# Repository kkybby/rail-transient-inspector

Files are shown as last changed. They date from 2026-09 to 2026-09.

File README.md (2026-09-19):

# LIMIT4

### Four limit-switch inputs for dual-actuator projects

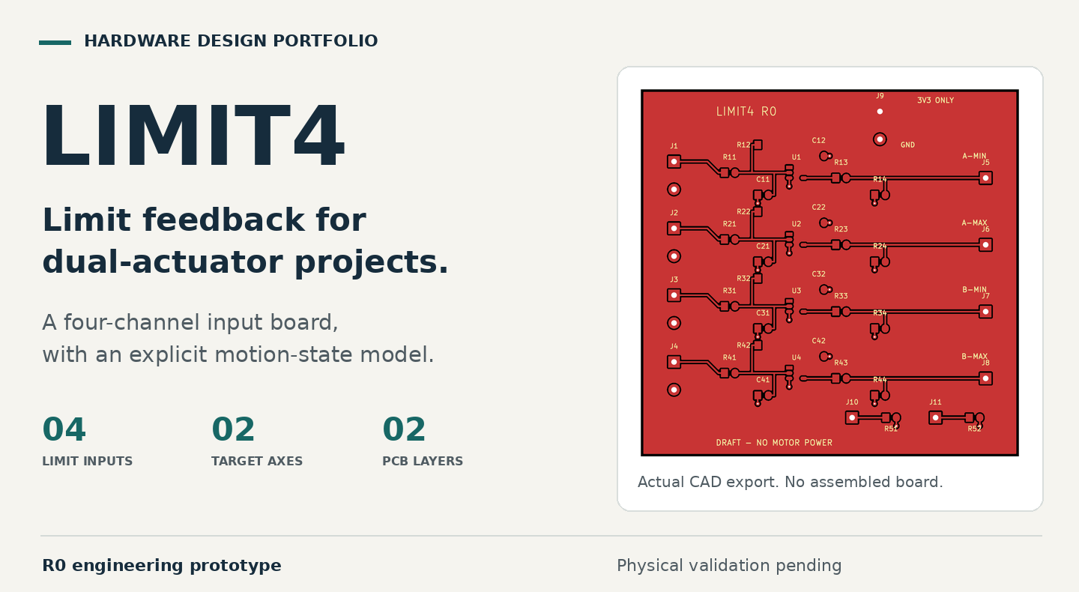
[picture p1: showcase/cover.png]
LIMIT4 hardware design portfolio, showing the actual PCB export


[中文介绍](README.zh-CN.md) | [Schematic](build/limit4-schematic.pdf) | [PCB source](hardware/limit4.kicad_pcb) | [Engineering details](docs/ENGINEERING.md)

**Stage: unbuilt engineering prototype.** The interface PCB and software checks are complete for this revision. The Pico 2 firmware is a dry-run build with motor outputs disabled.

## The problem

A small motorized prop has two distinct questions: did the controller accept the command, and did the mechanism reach its destination? A motor driver alone does not answer both.

LIMIT4 explores the interface between physical end stops and motion control. It provides four normally closed contact inputs for two actuator axes, with signal conditioning and a separate software model for stopped, moving, limit-open and fault states.

## The design contribution

**A board-level interface.** A two-layer, 68 x 66 mm PCB with four repeated input channels, local filtering, Schmitt-trigger conditioning and defined output biasing. Editable schematic, layout and project-local libraries are included.

**Explicit motion states.** The independent controller code handles directional limits, invalid reversal requests, driver-fault input, command timeout and communication expiry. A switch closing again does not automatically restart a stopped request. These behaviors are covered by host tests; physical stopping is not yet validated.

**Traceable engineering.** Component assumptions, reset and power-state analysis, source-to-layout checks and a bench qualification plan are retained with the design.

## What is new, and what is reused?

| This project's contribution | Existing upstream platform |
|---|---|
| LIMIT4 input-conditioning PCB and local CAD libraries | OpenDualMotorDriver motor-power motherboard |
| Independent motion-state code and dry-run wrapper | Existing bridge and current-sensing hardware |
| Interface analysis, tests and verification records | Published motherboard interfaces |

The reference platform is [OpenDualMotorDriver by Milos Rasic](https://github.com/MilosRasic98/OpenDualMotorDriver). The original power board has not been redesigned or qualified by this project. No original firmware or hardware photographs are presented as new work. Development of this extension was AI-assisted.

## Verification so far

The recorded KiCad checks report **zero ERC errors, zero DRC errors and zero unrouted items**. Cross-file checks cover 84 connected pin assignments and four NC pads. The motion-state tests pass 47 assertions, and the output-disabled program cross-compiles for Pico 2.

[Check records](build/check-summary.json) | [Software test record](build/host-tests.txt) | [Validation scope](docs/VALIDATION.md)

**Still to validate:** assembly, actual contacts, power sequencing, noise response and motor integration. A limit-loop opening cannot distinguish an endpoint from a broken wire. R0 is not released for fabrication, motor operation or personnel protection.

## Explore the work

Start with the [schematic PDF](build/limit4-schematic.pdf) and [PCB layout](build/pcb-top.png). The [engineering guide](docs/ENGINEERING.md) collects the BOM, interface mapping, calculations, source files and reproduction steps.

Hardware: [CERN-OHL-S-2.0](LICENSES/CERN-OHL-S-2.0.txt). Independent firmware: [MIT](firmware/LICENSE). [Attribution and upstream licence discrepancy](docs/PROVENANCE.md).

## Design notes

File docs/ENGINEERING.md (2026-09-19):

# LIMIT4 engineering reference

[Project overview](../README.md) | [中文作品介绍](../README.zh-CN.md)

This page contains detailed review and reproduction material. R0 is an unbuilt engineering prototype, not a manufacturing or motor-operation release.

## Design files

| Material | Source |
|---|---|
| Schematic | [PDF](../build/limit4-schematic.pdf), [editable KiCad file](../hardware/limit4.kicad_sch) |
| PCB | [Layout image](../build/pcb-top.png), [editable PCB](../hardware/limit4.kicad_pcb), [project settings](../hardware/limit4.kicad_pro) |
| Libraries | [Footprints](../hardware/LIMIT4.pretty), [symbols](../hardware/RTI.kicad_sym) |
| Parts and nets | [BOM qualification](../hardware/BOM.csv), [electrical manifest](../hardware/design.json) |
| Design reasoning | [Evidence](EVIDENCE.md), [qualification limits](QUALIFICATION.md), [power/reset states](STATES.md) |
| Integration | [Interface map and upstream issues](INTEGRATION.md) |
| Firmware | [Independent state model](../firmware/motion.hpp), [output-disabled Pico 2 program](../firmware/pico_dryrun.cpp) |
| Validation | [Scope and release gates](VALIDATION.md), [ERC](../build/erc.json), [DRC](../build/drc.json), [connectivity](../build/connectivity.txt), [host tests](../build/host-tests.txt) |
| Attribution | [Provenance](PROVENANCE.md), [hardware notice](../LICENSE-HARDWARE), [complete hardware licence](../LICENSES/CERN-OHL-S-2.0.txt), [software licence](../firmware/LICENSE) |

## Reproduction

Use KiCad 10.0.6 and the system Python installation that provides its matching `pcbnew` module. Native CAD and local libraries can also be opened directly without regeneration.

```sh
mkdir -p build
python3 tools/build_hardware.py
python3 tools/layout_schematic.py
python3 tools/polish_symbols.py
kicad-cli sch export pdf -o build/limit4-schematic.pdf hardware/limit4.kicad_sch
kicad-cli sch export netlist --format kicadxml -o build/limit4.xml hardware/limit4.kicad_sch
kicad-cli sch erc --format json -o build/erc.json hardware/limit4.kicad_sch
kicad-cli pcb drc --format json -o build/drc.json hardware/limit4.kicad_pcb
python3 tools/check_connectivity.py
c++ -std=c++17 -Wall -Wextra -Werror tests/motion_test.cpp -o /tmp/limit4-test
/tmp/limit4-test
python3 tools/build_showcase.py
```

The generator overwrites generated CAD. Incorporate any manual edits deliberately. Symbol polishing changes label visibility and the power-flag graphic only. Pin definitions, wires, net labels, PCB geometry and firmware are compared before and after that step; its record is in `build/symbol-display-audit.json`.

## Reading the checks

ERC, DRC and matching net names validate configured file rules and source consistency. They do not prove electrical margins, correct physical assembly, appropriate contact wetting, stop distance or safety. The 47 host assertions exercise software requests. The Pico 2 compile uses a dry-run program with physical PWM and RESET outputs held low.

Full passive part qualification, host silicon revision, power sequencing, motor/contact selection and physical tests remain open. Do not order parts or fabrication from the draft BOM without resolving the release gates.

## Presentation assets

The cover is built from `build/pcb-top.png`, an actual CAD copper-layer export. It is resized and placed in a typographic layout; it is not a product photograph or a claim that a board has been assembled. The source fingerprint is recorded in `showcase/asset-provenance.json`.

The repository overview is a GitHub README, not a deployed application website. The hardware project currently lives on `hardware/dual-actuator-controller-r0`; the software application remains on `main`.

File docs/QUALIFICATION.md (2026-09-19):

# Qualification boundaries / engineering review, 2026-09-19

Read this with EVIDENCE.md and STATES.md. These restrictions take precedence over any simplified interpretation of the numerical examples.

1. **RP2350 A2 erratum E9:** the normal input-leakage specification is not a worst-case substitute for the erratum. The 6k8 resistor is chosen within the documented external pull-down workaround; this does not establish all combinations of supply, ramp, internal pulls and disconnects. The 0.681 V unexpected-pull-up estimate in EVIDENCE.md excludes additional erratum-related current and therefore is NOT a guarantee for an A2 input with its internal pull-up enabled. Intended firmware disables internal pulls. Powered active-buffer high-drive margin also remains subject to the actual silicon and load. Do not use the approximately 120 uA typical erratum figure as a maximum.

2. **Supply-dependent specifications:** a VOH/VOL limit tested at 3.0 V and a receiver threshold specified at 3.3 V do not automatically prove every corner of an assumed 3.135–3.465 V shared rail. Interpolated Schmitt thresholds and RC crossing times are design estimates. The full range requires independent analysis and physical supply/temperature sweeps. Absolute maximum ratings are never an operating recommendation.

3. **Power sequencing:** separate buffer/host supplies are excluded. Below the logic devices' operating range, output behavior is unspecified. A common ground break is not covered by Ioff or the external pull-down. Partial-power and ramp calculations support a prototype concept only; no fail-safe guarantee is made.

4. **Reset provisions:** R51/R52 have an intended powered-driver bias calculation. They provide no protection if omitted or not connected to the verified motherboard nets. Unpowered driver input behavior, source-board stuffing, watchdog behavior and back-power paths still require qualification. RESET low means the specified electrical high-impedance/coast state, not instantaneous mechanical stopping.

5. **Contact and passive selection:** the NC contact must be qualified at the proposed sub-mA wetting current. Cable resistance/capacitance are engineering assumptions. Full passive MPNs, tolerances, voltage ratings, leakage, dimensions and footprints remain unresolved; the BOM is not a manufacturing authorization. Long-cable ESD, industrial inputs and surge protection are outside R0.

6. **Evidence interpretation:** ERC, DRC and netlist checks validate configured file rules and consistency, not these electrical assumptions. The host tests validate software requests only. The cross-compiled Pico program continuously holds real motor outputs off. There is no motor drive release, guaranteed stop latency or safety certification.

R0 remains NOT FOR FABRICATION and NOT FOR MOTOR OPERATION until these gates and the physical validation plan are resolved.

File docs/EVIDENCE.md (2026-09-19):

# Electrical evidence and calculations / R0

## Exact devices / documents

Extension IC: TI **SN74LVC1G14DBVR**, DBV 5-pin SOT-23. Product https://www.ti.com/product/SN74LVC1G14 ; data sheet **SCES218AA, October2025**, https://www.ti.com/lit/ds/symlink/sn74lvc1g14.pdf . No externally selectable silicon stepping was established; physical lot remains unknown. Input is high-impedance Schmitt CMOS; output is push-pull with Ioff support, not open drain. No internal resistor to VCC is assumed.

Host: upstream **Pico2/RP2350A module**. Pico2 datasheet Release5, build03/07/2026 d4e0f1799616: https://datasheets.raspberrypi.com/pico/pico-2-datasheet.pdf . RP2350 datasheet build2025-07-29 d126e9e-clean: https://datasheets.raspberrypi.com/rp2350/rp2350-datasheet.pdf . Actual module stepping must be identified; A2 erratum E9 is considered and B2 is not assumed.

Existing driver: **DRV8412DDWR**, DDW44 HTSSOP+PowerPAD. **SLES242H, July2024**: https://www.ti.com/lit/ds/symlink/drv8412.pdf . Product/EVM pages inspected: https://www.ti.com/product/DRV8412 and https://www.ti.com/tool/DRV8412DDWEVM . EVM user-guide download did not open in this session. No separate applicable errata was established from the inspected pages; this is not proof none exists. Full power-stage qualification remains open.

## Cell-by-cell evidence log

TI printed page equals PDF ordinal except unnumbered mechanical addendum. RP2350 viewer index is explicitly zero-based below.

| Document/table | Page | Row / column | Minimal relevant cell / condition | Supported conclusion |
|---|---|---|---|---|
| SCES218AA Table4-1 | print4/PDF4 | A,GND,Y,VCC / DBV | 2,3,4,5 | Exact DBV pin map |
| Same footnote1 | print4/PDF4 | NC | no internal connection, soldered | NC1 left electrically unconnected, pad retained |
| SCES218AA5.5 | print7/PDF7 | VT+ /3V min,max | 1.5,1.87V | Tested rising threshold |
| Same | print7/PDF7 | VT- /DBV /3V /-40..85C | 0.84,1.14V | Tested falling threshold; not DPW row |
| Same | print7/PDF7 | VT+4.5Vmax;VT-4.5Vmin | 2.74V;1.41V | Adjacent points for engineering interpolation |
| Same | print7/PDF7 | VOH /3V /-16mA /min | 2.4V | Loaded high output at tested condition |
| Same | print7/PDF7 | VOL /3V /16mA /max | 0.4V | Loaded low output at tested condition |
| Same | print7/PDF7 | II /VI5.5V or GND,VCC0..5.5 | +/-5uA | Input leakage, no assumed internal pull |
| Same | print7/PDF7 | Ioff /VCC0,VI or VO5.5V | +/-10uA | Qualified poweroff leakage |
| Same | print7/PDF7 | ICC /IO0,VI5.5V or GND | 10uAmax | Static rail-level current, not transient current |
| SCES218AA5.1/5.3 | print5/6/PDF5/6 | recommended input/output | 0..5.5V /0..VCC | No external12/24V inputs; abs-max not normal operation |
| SCES218AA7.2.3 Fig7-2 | print13/PDF13 | explanation | interpolation between table points | An engineering estimate, not a new independently tested limit |
| SCES218AA7.3 | print13/PDF13 | bypass | 0.1uF near VCC | Local Cx2 purpose |
| DBV0005A4214839/K08/2024 | PDF39, unnumbered | land pad/column/row pitch | 1.1x0.6mm /2.6mm /0.95mm | Custom DBV copper geometry |
| RP2350 Table1436,14.9.4 | print1339..1340,viewer1339..1340 | VIH/VIL at IOVDD3.3 | 2.0Vmin /0.8Vmax | GPIO compatibility comparison |
| Same | print1340,viewer1340 | VOH2mAmin /inputpullup | 2.62V /32..86kOhm | Reset drive and unexpected pull-up calculation |
| RP2350-E9 | print1366..1367,viewer1366..1367 | A2 mitigation | external pull-down8.2kOhm or less | 6k8+1% is within explicit workaround |
| SLES242H Table4-1 | print3/PDF3 | DDW RESET_AB/CD | pins16/6 | Not adjacent DRV8432 column |
| SLES242H5.7 | print7/PDF7 | RESETVIH/VIL,leak | 2Vmin /0.8Vmax /+/-100uA | Powered reset bias calculation |
| SLES242H6.3.3 | print13/PDF13 | reset mode | bridge high impedance | Coast/Hi-Z, not guaranteed mechanical braking |

E9's approximately120uA is typical, never treated as a guaranteed maximum. The explicit8.2k workaround is used instead. Active buffer drive helps when powered;6k8 also biases a disconnected/unpowered output. The standard GPIO1uA leakage applies only where the erratum does not invalidate it.

## Circuit / explicit assumptions

Engineering target: shared nominal3.3V, assumed3.135..3.465V; initial bench0..50C; NC contact+cable resistance<=10Ohm; cable capacitance<=1nF. These are qualification targets, not user equipment facts. Long-wire, industrial ESD/surge and independently powered hosts are excluded.

LOOP--330R--FILT; FILT--4k7--3V3; FILT--10nF--GND; U.A=FILT; U.Y--470R--ALLOW; ALLOW--6k8--GND. Four100nF bypasses. Resistors1%, filterC5% C0G targets. Exact passive MPNs are not yet qualified and are labelled SPEC_ONLY_MPN_PENDING in the BOM, preventing an unverified purchase recommendation.

Closed FILT worst at3.465V, series+contact343.3Ohm and pull4653Ohm:
`Vclosed <= 3.465*343.3/(4653+343.3) + 5uA*(4653||343.3) = 0.240V`.
Open FILT at minimum supply:
`Vopen >= 3.135-5uA*4747 = 3.111V`.
Contamination leakage must be added after qualification. The3V and4.5V threshold rows bracket an engineering interpolation as illustrated by Fig7-2; supply/temperature sweeps are still required. Wetting current is approximately0.62..0.70mA: do not assume an arbitrary micro-switch supports that low-current operation.

Using tested VOH2.4V, output resistor474.7Ohm and pull6732Ohm:
`VALLOW >= 2.4*6732/(6732+474.7)-1uA*6732 = 2.235V`, margin0.235V over GPIO VIH2.0V at3.3V. Tested VOL0.4V is below0.8V. The loaded specification is evaluated at its actual test point; extending to the full assumed common-rail range remains prototype qualification. Actual static load<0.52mA per output, below the16mA test condition. Intended resistor loss is only a few mW.

Buffer poweroff: `10uA*6868Ohm =0.069V`. Unexpected host internal pull-up32kOhm at3.465V gives `3.465*6868/(32000+6868)=0.612V`; adding0.069V yields0.681V<0.8V under this defined model. This does not cover ground loss or an actively driven host output. GPIO inputs have internal pulls disabled in the intended firmware.

Accidental opposing push-pull outputs are current-limited nominally by470R: `3.465/465.3=7.45mA`. This is mitigation of accidental DC contention, not a valid operating mode or a verified transient-clamp budget. Positive/negative transients and separate supply behavior are not certified.

Filter open tau maximum=`4747*(10.5nF+1nF)=54.59us`. The table-based interpolated rising threshold at3.465V is about2.14V. Crossing is on the order of50..65us for these assumptions. This is not a motor-stop guarantee: polling, scheduling, bounce, driver behavior and inertia add delay. Startup capacitor charging can temporarily make ALLOWhigh, so the controller requires stable inputs and explicit arm. No automatic restart is implemented.

Optional RESET2k2 pulls: powered-driver leakage100uA times Rmax2222Ohm is0.2222V<0.8V. At GPIO VOHmin2.62V the load including100uA is about1.30mA, below the2mA output test; high-level margin is0.62V. Driver leakage was specified under powered conditions; fully independent poweroff still needs investigation. The driver's ~1kOhm internal pull-down row applies to each OUTPUT half-bridge, not RESET. No invented RESET internal pull is used.

## Classification

Cx2: data-sheet recommended bypass. R x1/x2/x3/x4, Cx1,R51/R52: computed engineering selections under stated assumptions, require physical validation. Host mapping: source-verified but assembled continuity pending. No unverified motor-current, clamp/ESD or connector behavior enters a production connection table. R0 is not a production release.

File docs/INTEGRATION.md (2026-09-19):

# Integration / engineering suggestion only

This is a wired expansion, not a mechanically interchangeable motherboard. There are no motor-current paths on LIMIT4. Verify actual board revision and continuity before soldering.

| LIMIT4 | Purpose | Intended upstream net |
|---|---|---|
| J9.1 | Shared3V3 | CN7.1 /host3V3 |
| J9.2 | Ground | CN7.5/GND |
| J5.1 | A_MIN ALLOW | GPIO16/CN7.2/SPI_MISO |
| J6.1 | A_MAX ALLOW | GPIO17/CN7.4/SPI_CS |
| J7.1 | B_MIN ALLOW | GPIO18/CN7.6/SPI_SCK |
| J8.1 | B_MAX ALLOW | GPIO19/CN7.3/SPI_MOSI |
| J10.1 | Optional reset pull | RESET_AB/GPIO12/DRV8412DDW16 |
| J11.1 | Optional reset pull | RESET_CD/GPIO9/DRV8412DDW6 |
| J1..J4.1 | Contact signal | NC switch to corresponding pin2 |
| J1..J4.2 | Contact return | GND |

Mapping evidence: upstream schematic pages2/3 and BoardConfig.h at pinned commit; TI SLES242H Table4-1 DDW column. Classification: engineering connection suggestions after source review, pending physical continuity and power-state checks. The4k7/6k8/470/330 and2k2 parts' calculations are in EVIDENCE.md.

All J footprints are plated solder-wire pads with1mm holes; pin1 is rectangular. No mating connector/strain relief/wire model is qualified. Upstream CN7 drawing has a part-name suggesting a different contact count; do not assume an off-the-shelf cable maps correctly.

Axis A is bridgeAB, PWM_A GPIO11/PWM_B GPIO13. B is bridgeCD, PWM_C GPIO8/PWM_D GPIO10. Direction versus actual travel must be checked. Four limit signals consume the original SPI GPIOs; SPI peripherals cannot run concurrently.

Review finding: firmware axis0 samples GPIO26/ACS722_OUT1, while schematic links OUT1 to CD and OUT2/GPIO27 to AB. This is a source inconsistency to investigate, not a measured hardware failure. R0 uses no current measurement for protection. Confirm physical netlist/mapping before current-based stopping. Existing driver OCP is not automatically appropriate for a small motor/gearbox.

Original power schematic shows external5V attached to Pico VBUS and external3V3 arrangements. USB plus external power, regulator reverse current and actual stuffing need a separate audit. Avoid simultaneous unverified power sources. Native source/README voltage claims are not adopted as our ratings.

Real drive is compile-blocked. Required before enabling: motor full model/voltage/stall current/inertia, micro-switch model/wetting requirements, guard/stop strategy, actual part revisions, power-sequence tests. Driver RESETlow gives Hi-Z/coast with the specified weak output pull-down; it does not guarantee instantaneous braking or zero travel.

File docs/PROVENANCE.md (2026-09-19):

# Provenance / changes / licensing

Upstream: Miloš Rašić, OpenDualMotorDriver, commit `9a938240a8053269b1b8786dccdb6d541cb7396c`.

Original files inspected: `Hardware/ProPrj_Dual_Motor_Driver_2026-05-02.epro`, three schematic PNGs, `Firmware/PicoDualMotorDriver/BoardConfig.h`, `DualMotorController.cpp`, README, LICENSE and LICENSE-HARDWARE. The epro is an EasyEDA Pro archive, editor metadata 2.2.45.4. Its source motherboard has LT8350-based12V gate-drive power, a5V converter and a3.3V regulator; the derivative has not requalified these sections. No upstream power ratings are adopted as our measured specifications.

**Licence discrepancy:** the pinned README/Hardware notice say firmware and host software are MIT; the actual root LICENSE is the GNU GPL version3 text. Our earlier claim that all software was MIT was overbroad. This release does not copy, modify or redistribute upstream firmware. The new small state machine and dry-run wrapper are independent code; pin/net assignments are documented interfaces. Any later reuse must first resolve the applicable terms.

The upstream `LICENSE-HARDWARE` explicitly assigns CERN-OHL-S-2.0 to the hardware. The new extension hardware, schematic, board, electrical manifest, design generator and technical hardware documents are offered under CERN-OHL-S-2.0. Preserve attribution and source location. No endorsement by the original author, TI, Raspberry Pi, CERN or Element14 is implied.

New contribution: four NC front ends, defined default-low outputs, two external driver-reset pulls, four-input harness map, independent state machine, tests, native CAD and source-to-board checks. Original main bridge PCB remains unmodified and linked, not claimed as a newly routed derivative. Original photographs are not used as photographs of our product.

Official licence: https://ohwr.org/licences/ . The authoritative licence, not this summary, governs. AI-assisted design; no physical board, motor measurement or customer result is claimed.

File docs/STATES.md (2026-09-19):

# State / failure review

| Condition | Expected in stated model | Residual risk |
|---|---|---|
| Powered/NCclosed | FILTlow/ALLOWhigh | Contact wetting must be qualified |
| NCopens/either loopwire breaks | FILThigh/ALLOWlow; directional request stopped | Cannot distinguish endpoint/wirebreak; short defeats detection |
| MCU reset/high-Z | External2k2 aim to hold RESETlow | Physical rework and driver-powered leakage must be tested |
| RESET high/low | Enable /Hi-Z according to TI | Dry-run never drives high |
| GPIO mistakenly output |470R mitigates contention | Invalid operating state, no correctness claim |
| Buffer off/hoston |Ioff and6k8 model yields low | Shared supplies are intended; verify GPIO/ground |
| Bufferon/hostoff |Buffer can drive hostpad |Independent supplies prohibited; abs-max not permission |
| Ramp/brownout |Logic below supplymin unspecified |Explicit arm; measure reset sequence |
| Sleep/wake |Require reset and newarm |Sleep routine not implemented |
| Driverfault/both limitsopen |All requests disabled |OCP may not protect gearbox |
| Communication expires |Requests cleared at500ms policy |Host test only; no measured latency |
| Firmware lockup |Watchdog100ms request/reset pulls |Actual watchdog behavior untested |
| Reverse request while moving |Rejected |Qualified PWM/deadtime backend not implemented |
| Contact recloses after stop |No automatic restart |Bounce/EMI still require testing |
| Common groundbreak |Undefined references |Not fail-safe; independent cutoff needed |

No optocoupler, MOSFET, level translator or TVS is installed on this controlled shared-rail dry-contact interface. Their absence restricts use; it is not a robustness claim. Long cables/industrial24V sensors need a separate protection design. Local100nF capacitors bypass each gate;10nF filters and external pulls have explicit calculations, not generic boilerplate.

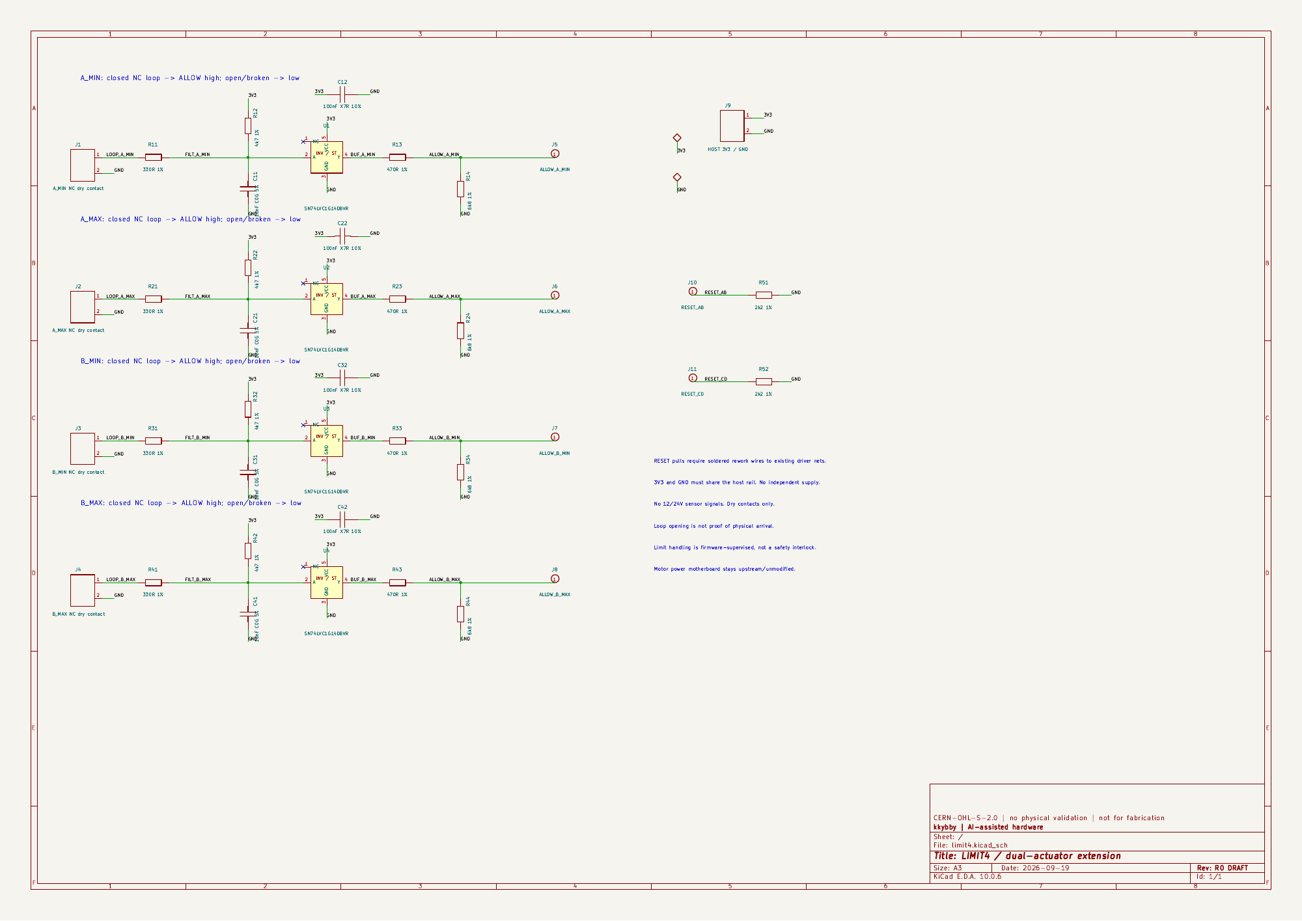
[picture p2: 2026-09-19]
build/schematic.png

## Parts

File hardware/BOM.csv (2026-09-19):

Reference | Value | Candidate_MPN | Footprint | Qualification
J1 | A_MIN NC dry contact |  | 1mm solder-wire holes | Wire termination only; no mating connector claimed
R11 | 330R 1% | SPEC_ONLY_MPN_PENDING | 0805 | Exact TI IC checked; passive sourcing/assembly approval pending
R12 | 4k7 1% | SPEC_ONLY_MPN_PENDING | 0805 | Exact TI IC checked; passive sourcing/assembly approval pending
C11 | 10nF C0G 5% | SPEC_ONLY_MPN_PENDING | 0805 | Exact TI IC checked; passive sourcing/assembly approval pending
U1 | SN74LVC1G14DBVR | SN74LVC1G14DBVR | DBV-5 | Exact TI IC checked; passive sourcing/assembly approval pending
C12 | 100nF X7R 10% | SPEC_ONLY_MPN_PENDING | 0805 | Exact TI IC checked; passive sourcing/assembly approval pending
R13 | 470R 1% | SPEC_ONLY_MPN_PENDING | 0805 | Exact TI IC checked; passive sourcing/assembly approval pending
R14 | 6k8 1% | SPEC_ONLY_MPN_PENDING | 0805 | Exact TI IC checked; passive sourcing/assembly approval pending
J5 | ALLOW_A_MIN |  | 1mm solder-wire holes | Wire termination only; no mating connector claimed
J2 | A_MAX NC dry contact |  | 1mm solder-wire holes | Wire termination only; no mating connector claimed
R21 | 330R 1% | SPEC_ONLY_MPN_PENDING | 0805 | Exact TI IC checked; passive sourcing/assembly approval pending
R22 | 4k7 1% | SPEC_ONLY_MPN_PENDING | 0805 | Exact TI IC checked; passive sourcing/assembly approval pending
C21 | 10nF C0G 5% | SPEC_ONLY_MPN_PENDING | 0805 | Exact TI IC checked; passive sourcing/assembly approval pending
U2 | SN74LVC1G14DBVR | SN74LVC1G14DBVR | DBV-5 | Exact TI IC checked; passive sourcing/assembly approval pending
C22 | 100nF X7R 10% | SPEC_ONLY_MPN_PENDING | 0805 | Exact TI IC checked; passive sourcing/assembly approval pending
R23 | 470R 1% | SPEC_ONLY_MPN_PENDING | 0805 | Exact TI IC checked; passive sourcing/assembly approval pending
R24 | 6k8 1% | SPEC_ONLY_MPN_PENDING | 0805 | Exact TI IC checked; passive sourcing/assembly approval pending
J6 | ALLOW_A_MAX |  | 1mm solder-wire holes | Wire termination only; no mating connector claimed
J3 | B_MIN NC dry contact |  | 1mm solder-wire holes | Wire termination only; no mating connector claimed
R31 | 330R 1% | SPEC_ONLY_MPN_PENDING | 0805 | Exact TI IC checked; passive sourcing/assembly approval pending
R32 | 4k7 1% | SPEC_ONLY_MPN_PENDING | 0805 | Exact TI IC checked; passive sourcing/assembly approval pending
C31 | 10nF C0G 5% | SPEC_ONLY_MPN_PENDING | 0805 | Exact TI IC checked; passive sourcing/assembly approval pending
U3 | SN74LVC1G14DBVR | SN74LVC1G14DBVR | DBV-5 | Exact TI IC checked; passive sourcing/assembly approval pending
C32 | 100nF X7R 10% | SPEC_ONLY_MPN_PENDING | 0805 | Exact TI IC checked; passive sourcing/assembly approval pending
R33 | 470R 1% | SPEC_ONLY_MPN_PENDING | 0805 | Exact TI IC checked; passive sourcing/assembly approval pending
R34 | 6k8 1% | SPEC_ONLY_MPN_PENDING | 0805 | Exact TI IC checked; passive sourcing/assembly approval pending
J7 | ALLOW_B_MIN |  | 1mm solder-wire holes | Wire termination only; no mating connector claimed
J4 | B_MAX NC dry contact |  | 1mm solder-wire holes | Wire termination only; no mating connector claimed
R41 | 330R 1% | SPEC_ONLY_MPN_PENDING | 0805 | Exact TI IC checked; passive sourcing/assembly approval pending
R42 | 4k7 1% | SPEC_ONLY_MPN_PENDING | 0805 | Exact TI IC checked; passive sourcing/assembly approval pending
C41 | 10nF C0G 5% | SPEC_ONLY_MPN_PENDING | 0805 | Exact TI IC checked; passive sourcing/assembly approval pending
U4 | SN74LVC1G14DBVR | SN74LVC1G14DBVR | DBV-5 | Exact TI IC checked; passive sourcing/assembly approval pending
C42 | 100nF X7R 10% | SPEC_ONLY_MPN_PENDING | 0805 | Exact TI IC checked; passive sourcing/assembly approval pending
R43 | 470R 1% | SPEC_ONLY_MPN_PENDING | 0805 | Exact TI IC checked; passive sourcing/assembly approval pending
R44 | 6k8 1% | SPEC_ONLY_MPN_PENDING | 0805 | Exact TI IC checked; passive sourcing/assembly approval pending
J8 | ALLOW_B_MAX |  | 1mm solder-wire holes | Wire termination only; no mating connector claimed
J9 | HOST 3V3 / GND |  | 1mm solder-wire holes | Wire termination only; no mating connector claimed
J10 | RESET_AB |  | 1mm solder-wire holes | Wire termination only; no mating connector claimed
R51 | 2k2 1% | SPEC_ONLY_MPN_PENDING | 0805 | Exact TI IC checked; passive sourcing/assembly approval pending
J11 | RESET_CD |  | 1mm solder-wire holes | Wire termination only; no mating connector claimed
R52 | 2k2 1% | SPEC_ONLY_MPN_PENDING | 0805 | Exact TI IC checked; passive sourcing/assembly approval pending

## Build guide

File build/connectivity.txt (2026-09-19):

84 populated pin/net assignments and 4 NC pads match schematic, PCB and manifest.
drc.json errors= 0 warnings= 0 unconnected= 0
erc.json errors= 0 warnings= 0 unconnected= 0

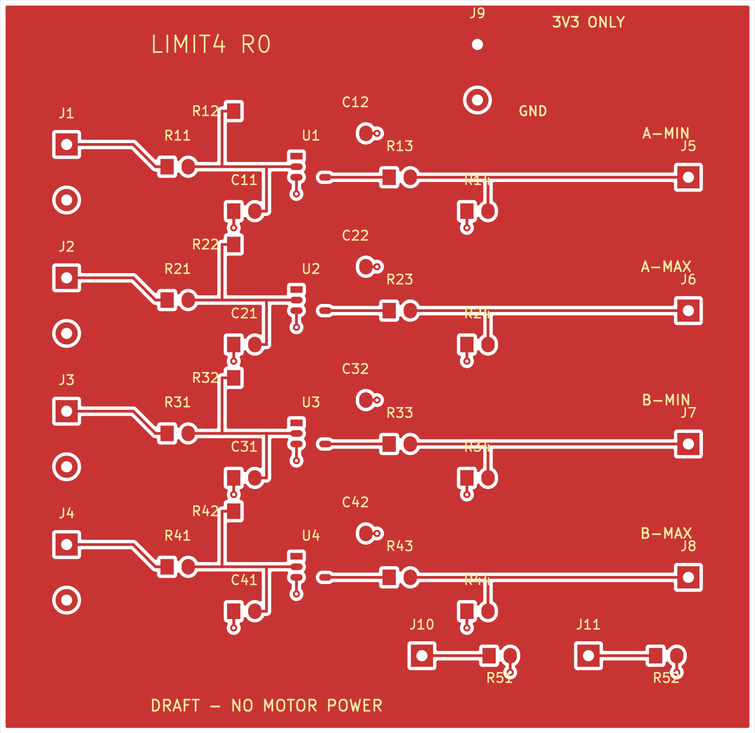
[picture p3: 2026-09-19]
build/pcb-top.png

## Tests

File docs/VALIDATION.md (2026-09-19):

# Validation record and remaining release gates

## Actually executed, 2026-09-19

| Check | Actual result |
|---|---|
| KiCad version | 10.0.6 |
| Native schematic/PCB | Generated and opened by KiCad CLI; PDF/SVG exports produced |
| ERC | 0 errors, 0 warnings |
| DRC | 0 errors, 0 warnings, 0 unconnected items |
| Manifest/schematic/PCB mapping | 41 components, 84 connected pin assignments, 4 NC pads checked |
| Independent host controller | 47 assertions passed using g++ C++17, -Wall -Wextra -Werror |
| Pico 2 cross-compilation | Success, pinned official Pico SDK 2.2.0 |
| Resulting ELF size | text 35168 bytes, data 0 bytes, BSS 3792 bytes |
| Assembly, flashing, motor tests | Not performed |

CAD source commit: `394ce1f6ac9a20584c89738f3ebd1a408357ee30`.
[CAD CI and generated-file publication](https://github.com/kkybby/rail-transient-inspector/actions/runs/35427853316).
Actual reports: [check summary](../build/check-summary.json), [connectivity](../build/connectivity.txt), [ERC](../build/erc.json), [DRC](../build/drc.json), [host assertions](../build/host-tests.txt).

Firmware source commit: `59efa8e02bd895e27b4777502ecefca23f3a303f`.
[Actual Pico 2 compile run](https://github.com/kkybby/rail-transient-inspector/actions/runs/35427472611).
Pico SDK commit: `a1438dff1d38bd9c65dbd693f0e5db4b9ae91779`.
Board target: `pico2`, `PICO_NO_PICOTOOL=1`; ELF/bin/hex compiled, no UF2 creation claimed. Firmware source has not changed after this successful run. The separate compile artifact contains logs and binaries; no flashing or hardware result follows from compilation.

Read [QUALIFICATION.md](QUALIFICATION.md) with the circuit estimates. No rule errors have been waived to manufacture a passing status. However, a passing automated check cannot establish physical correctness, appropriate component choice or safety.

## Physical release gates, still open

1. Confirm actual Pico 2 stepping and host PCB/epro/schematic correspondence, supply and USB connections.
2. Qualify full passive MPNs, footprint/body dimensions, voltage/tolerance/temperature/leakage and effective capacitance. Select the actual micro-switch for sub-mA wetting current.
3. With no motors connected, verify all loop states, unplugged wires, host harness, input modes and levels over the intended supply range. Record raw-input and ALLOW waveforms.
4. Characterize startup pulses, switch bounce and interference. Stop latency and stop distance must include mechanics and scheduling, not only an RC calculation.
5. Check reset, watchdog, invalid/reversed commands, limit-at-start, both loops open, driver fault, communication expiry and no automatic restart. A loop opening must not be labelled physical arrival without independent evidence.
6. Verify actual external reset-pull wiring and bias with each power state. Powered-input leakage does not cover all independent-off states.
7. Audit the upstream supply and current-channel mapping. Lock motor voltage/stall current/inertia, current limit, fuse, braking and guarding before implementing a real-drive backend.
8. Only then perform controlled low-energy motor testing with an independent cutoff and recorded results.

No fabrication Gerber package is issued in R0. Editable CAD is for review and iteration. No personnel-protection, human-trapping lock, lifting, vehicle or unguarded application is qualified. Firmware deliberately keeps physical outputs disabled.

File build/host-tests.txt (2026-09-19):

47 state-machine assertions passed; host logic only, no motor tests.

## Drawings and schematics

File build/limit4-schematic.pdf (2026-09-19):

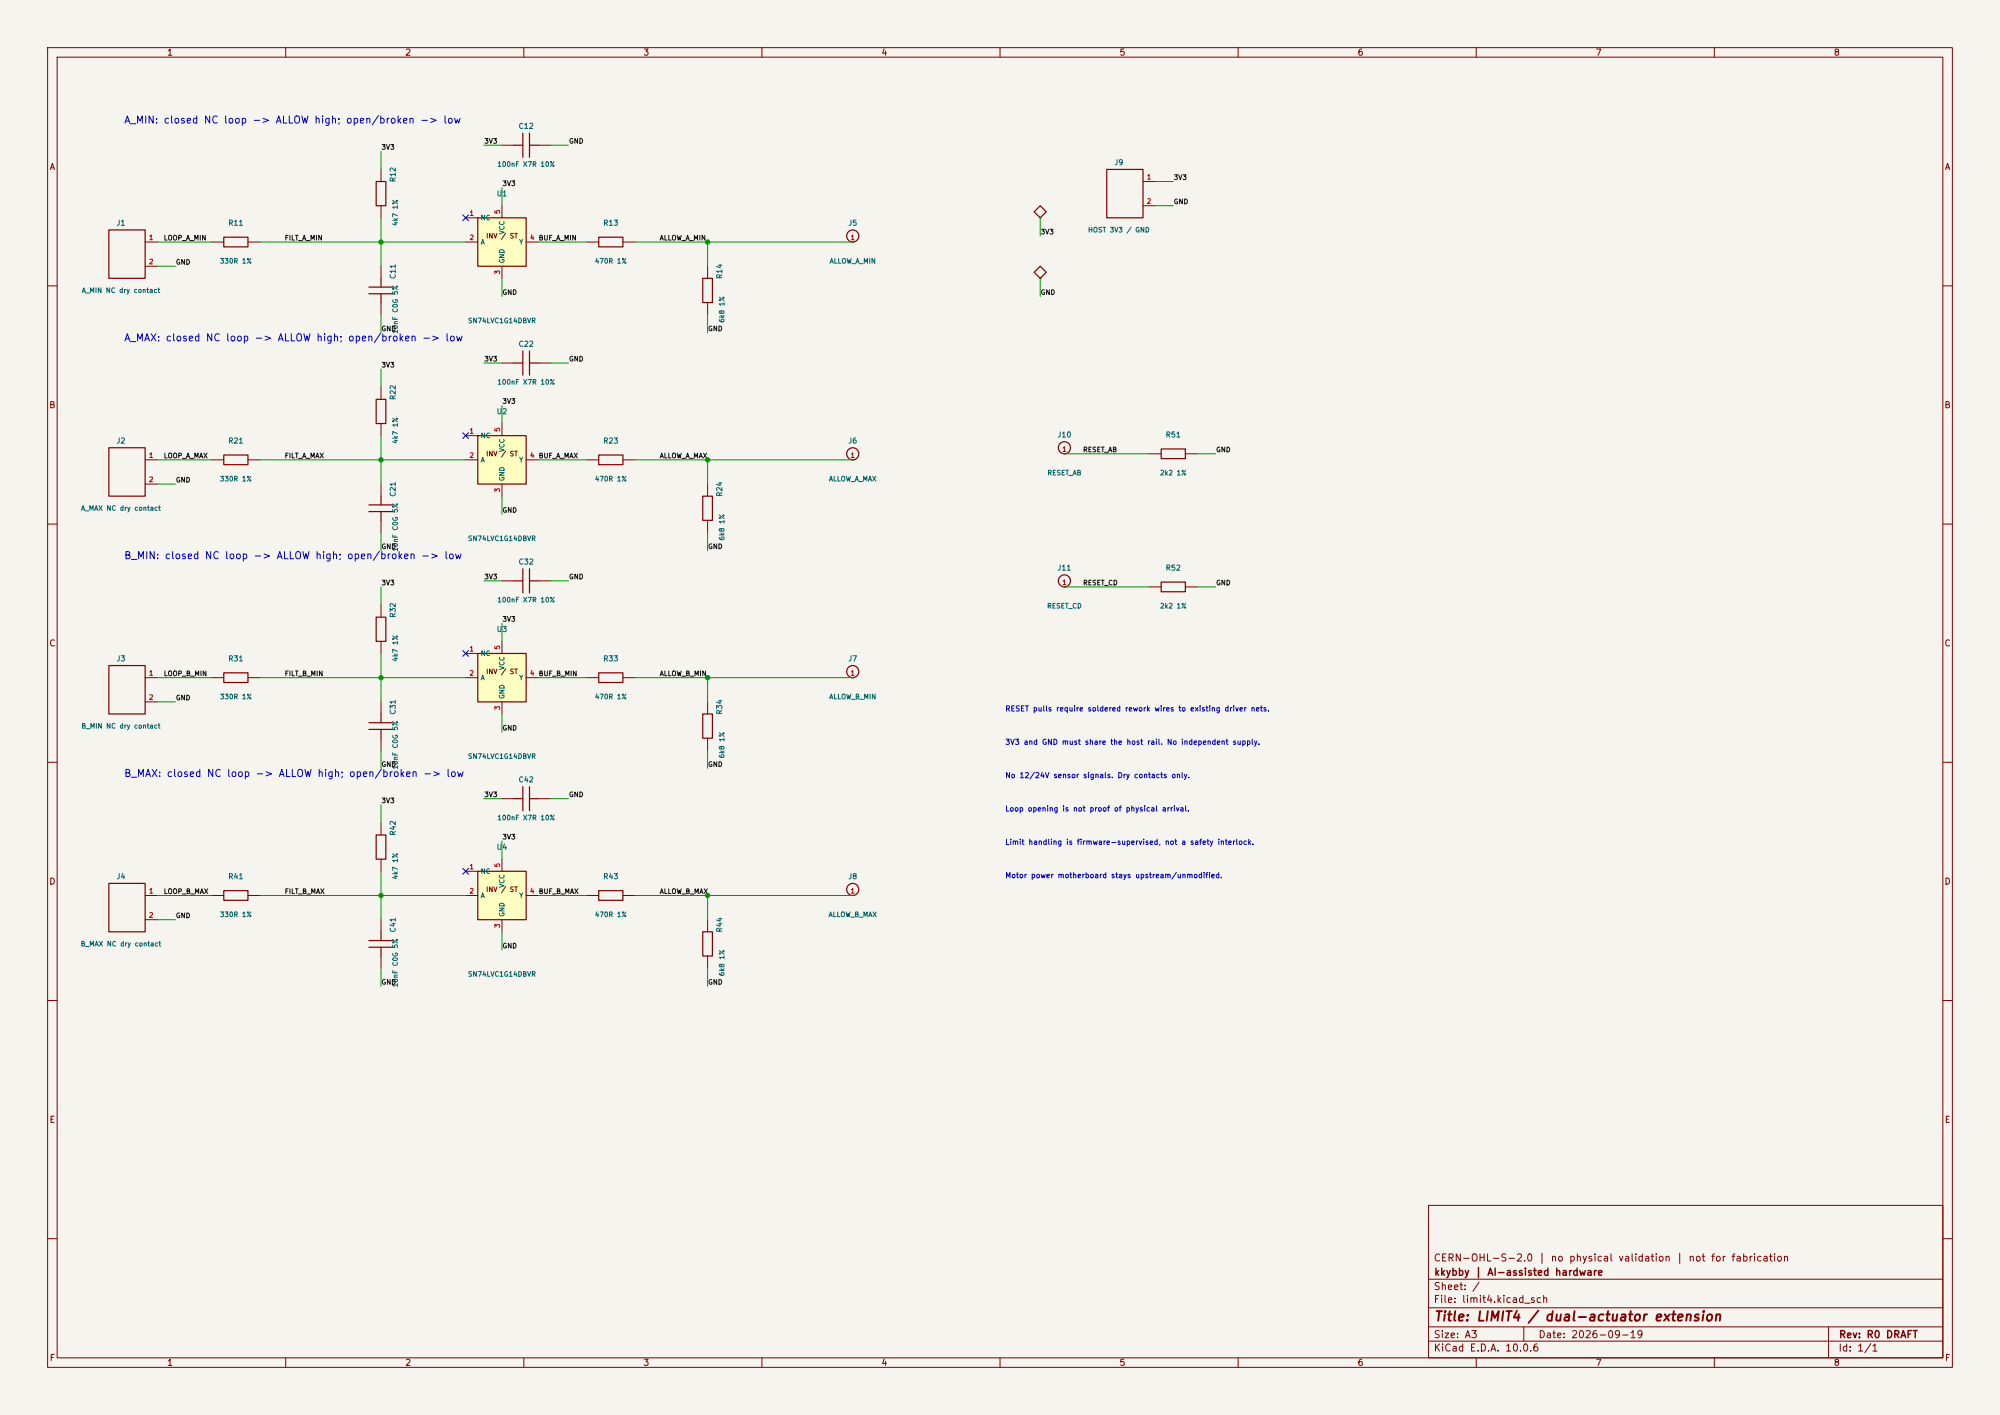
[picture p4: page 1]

A_MIN: closed NC loop -> ALLOW high; open/broken -> low

A_MAX: closed NC loop -> ALLOW high; open/broken -> low

CERN-OHL-S-2.0 | no physical validation | not for fabrication R24 6k8 1%

B_MIN: closed NC loop -> ALLOW high; open/broken -> low

RESET pulls require soldered rework wires to existing driver nets.

Loop opening is not proof of physical arrival. B_MAX: closed NC loop -> ALLOW high; open/broken -> low

kkybby | AI-assisted hardware
Sheet: /
File: limit4.kicad_sch
Title: LIMIT4 / dual-actuator extension

Size: A3 | Rev: R0 DRAFT | F Date: 2026-09-19
KiCad E.D.A. 10.0.6 | Id: 1/1

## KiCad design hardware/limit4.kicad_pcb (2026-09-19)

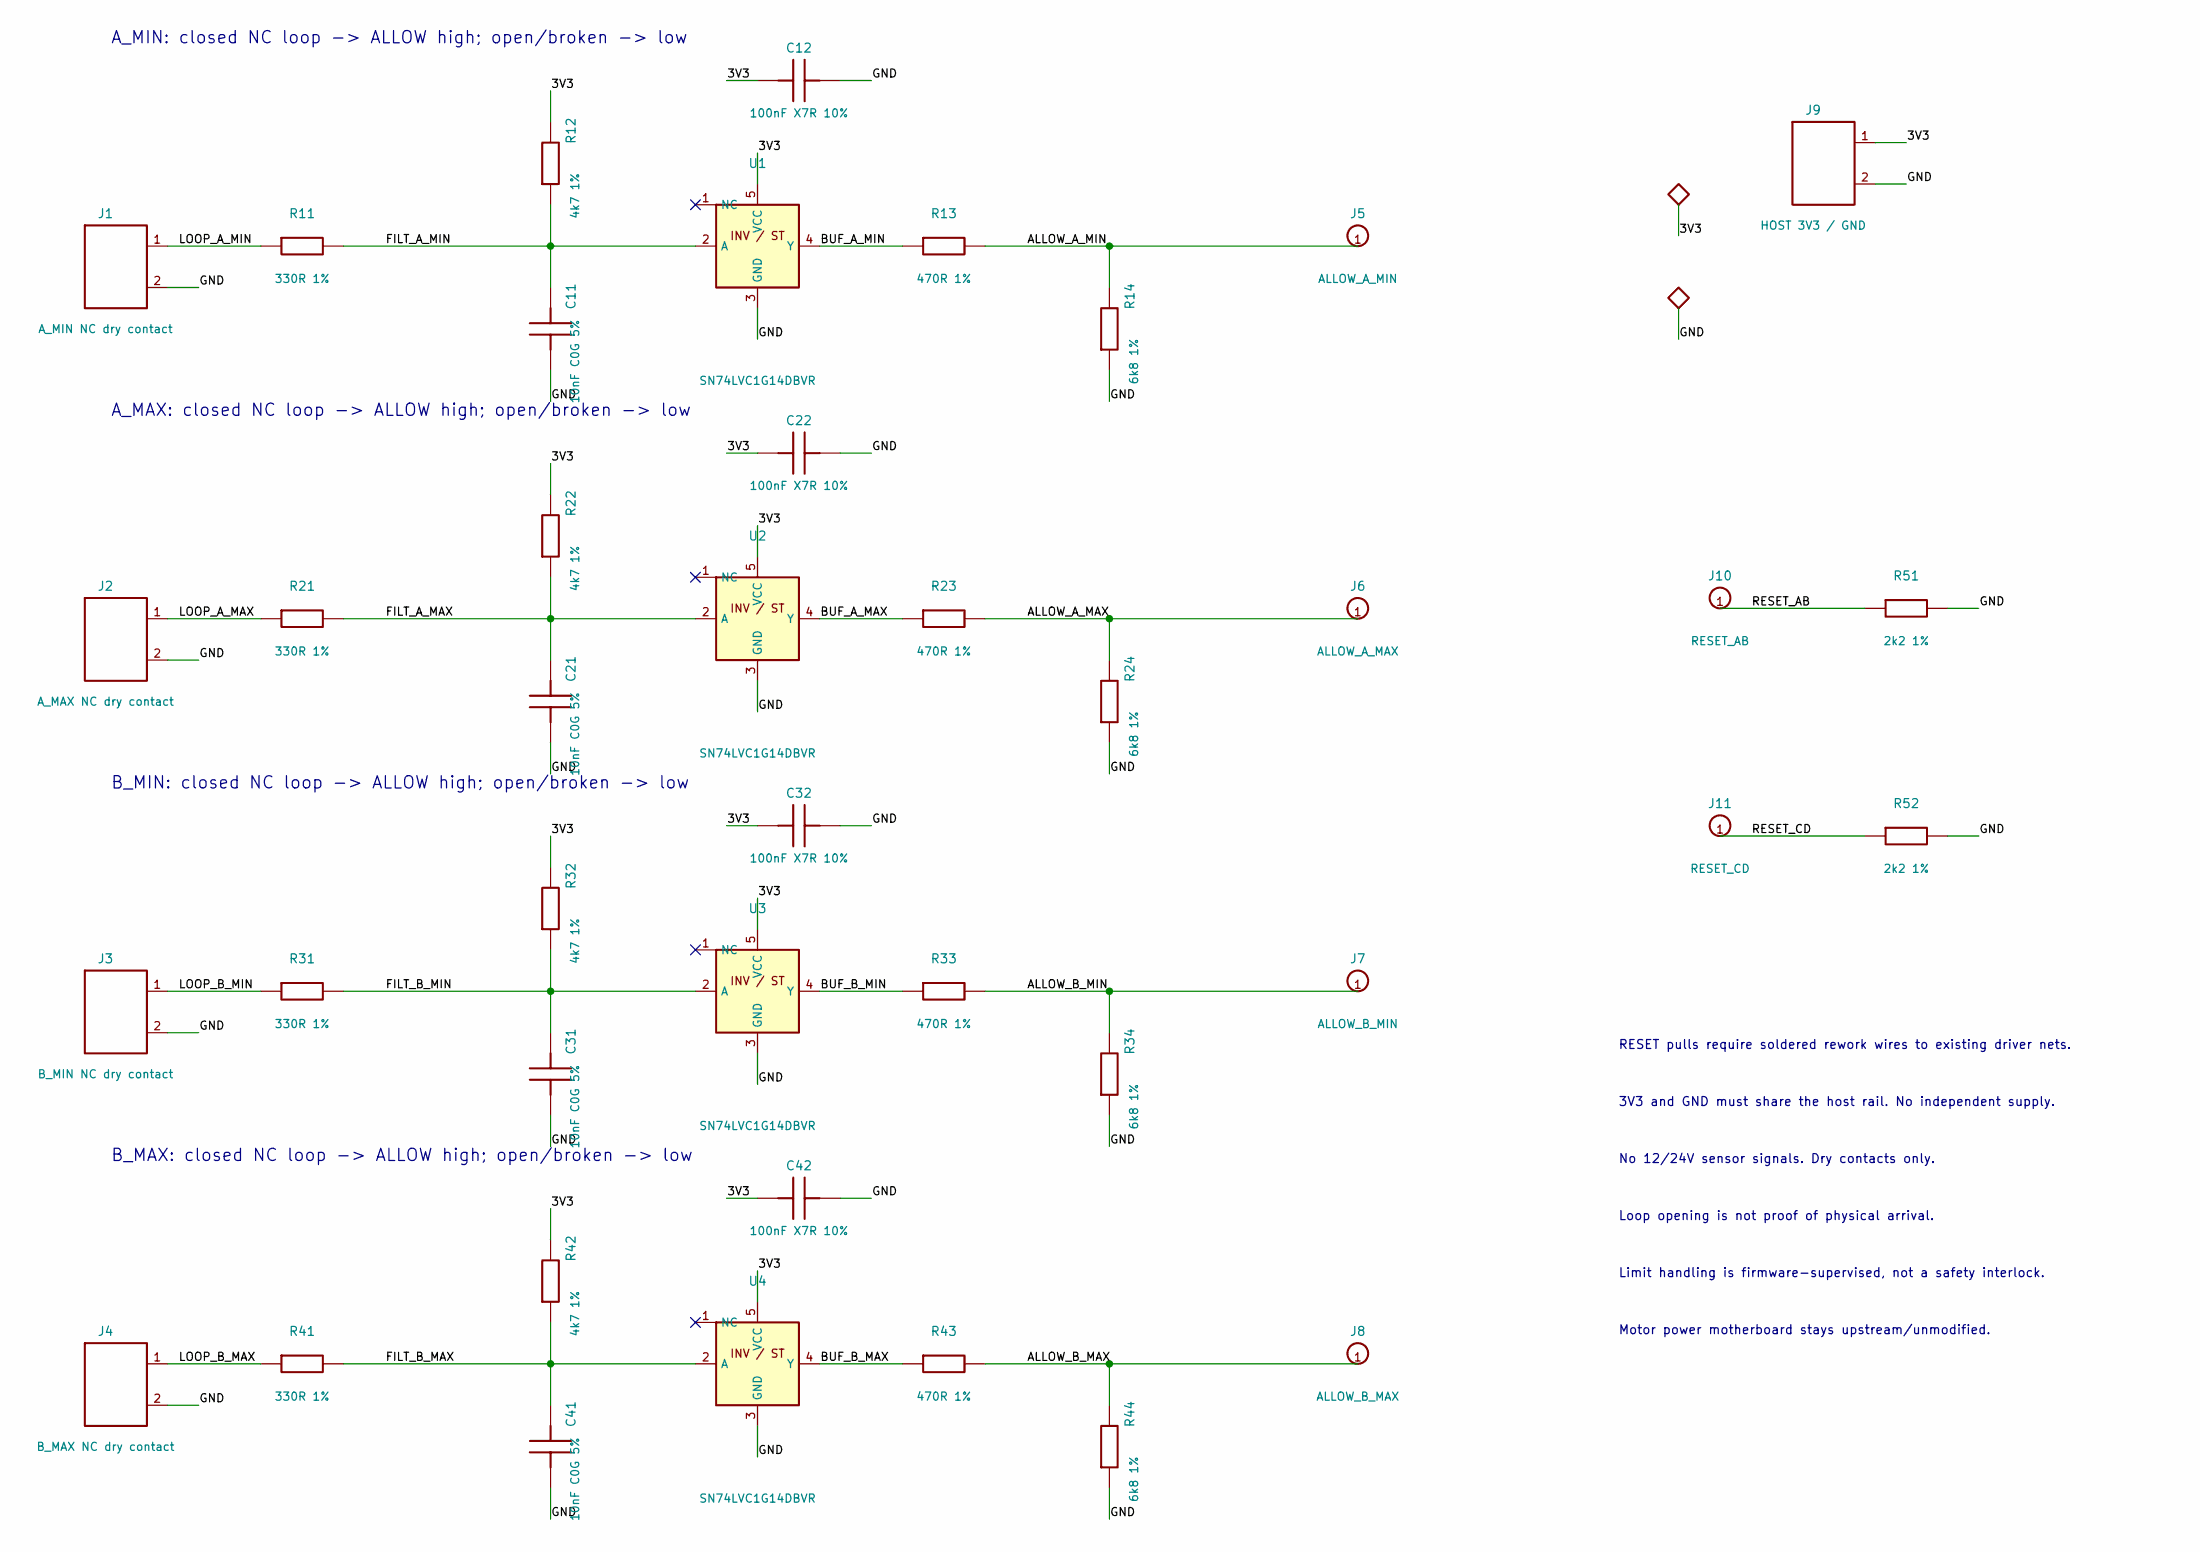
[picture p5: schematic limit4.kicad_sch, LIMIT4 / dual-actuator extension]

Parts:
C11, C21, C31, C41: 10nF C0G 5%; 0805
C12, C22, C32, C42: 100nF X7R 10%; 0805
J1: A_MIN NC dry contact; J2
J2: A_MAX NC dry contact; J2
J3: B_MIN NC dry contact; J2
J4: B_MAX NC dry contact; J2
J5: ALLOW_A_MIN; J1
J6: ALLOW_A_MAX; J1
J7: ALLOW_B_MIN; J1
J8: ALLOW_B_MAX; J1
J9: HOST 3V3 / GND; J2
J10: RESET_AB; J1
J11: RESET_CD; J1
R11, R21, R31, R41: 330R 1%; 0805
R12, R22, R32, R42: 4k7 1%; 0805
R13, R23, R33, R43: 470R 1%; 0805
R14, R24, R34, R44: 6k8 1%; 0805
R51, R52: 2k2 1%; 0805
U1, U2, U3, U4: SN74LVC1G14DBVR; DBV5

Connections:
3V3: C12.1, C22.1, C32.1, C42.1, J9.1, R12.2, R22.2, R32.2, R42.2, U1.5 (VCC), U2.5 (VCC), U3.5 (VCC), U4.5 (VCC)
ALLOW_A_MAX: J6.1, R23.2, R24.2
ALLOW_A_MIN: J5.1, R13.2, R14.2
ALLOW_B_MAX: J8.1, R43.2, R44.2
ALLOW_B_MIN: J7.1, R33.2, R34.2
BUF_A_MAX: R23.1, U2.4 (Y)
BUF_A_MIN: R13.1, U1.4 (Y)
BUF_B_MAX: R43.1, U4.4 (Y)
BUF_B_MIN: R33.1, U3.4 (Y)
FILT_A_MAX: C21.2, R21.2, R22.1, U2.2 (A)
FILT_A_MIN: C11.2, R11.2, R12.1, U1.2 (A)
FILT_B_MAX: C41.2, R41.2, R42.1, U4.2 (A)
FILT_B_MIN: C31.2, R31.2, R32.1, U3.2 (A)
GND: C11.1, C12.2, C21.1, C22.2, C31.1, C32.2, C41.1, C42.2, J1.2, J2.2, J3.2, J4.2, J9.2, R14.1, R24.1, R34.1, R44.1, R51.2, R52.2, U1.3 (GND), U2.3 (GND), U3.3 (GND), U4.3 (GND)
LOOP_A_MAX: J2.1, R21.1
LOOP_A_MIN: J1.1, R11.1
LOOP_B_MAX: J4.1, R41.1
LOOP_B_MIN: J3.1, R31.1
RESET_AB: J10.1, R51.1
RESET_CD: J11.1, R52.1

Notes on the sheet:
A_MIN: closed NC loop -> ALLOW high; open/broken -> low
A_MAX: closed NC loop -> ALLOW high; open/broken -> low
B_MIN: closed NC loop -> ALLOW high; open/broken -> low
B_MAX: closed NC loop -> ALLOW high; open/broken -> low
RESET pulls require soldered rework wires to existing driver nets.
3V3 and GND must share the host rail. No independent supply.
No 12/24V sensor signals. Dry contacts only.
Loop opening is not proof of physical arrival.
Limit handling is firmware-supervised, not a safety interlock.
Motor power motherboard stays upstream/unmodified.

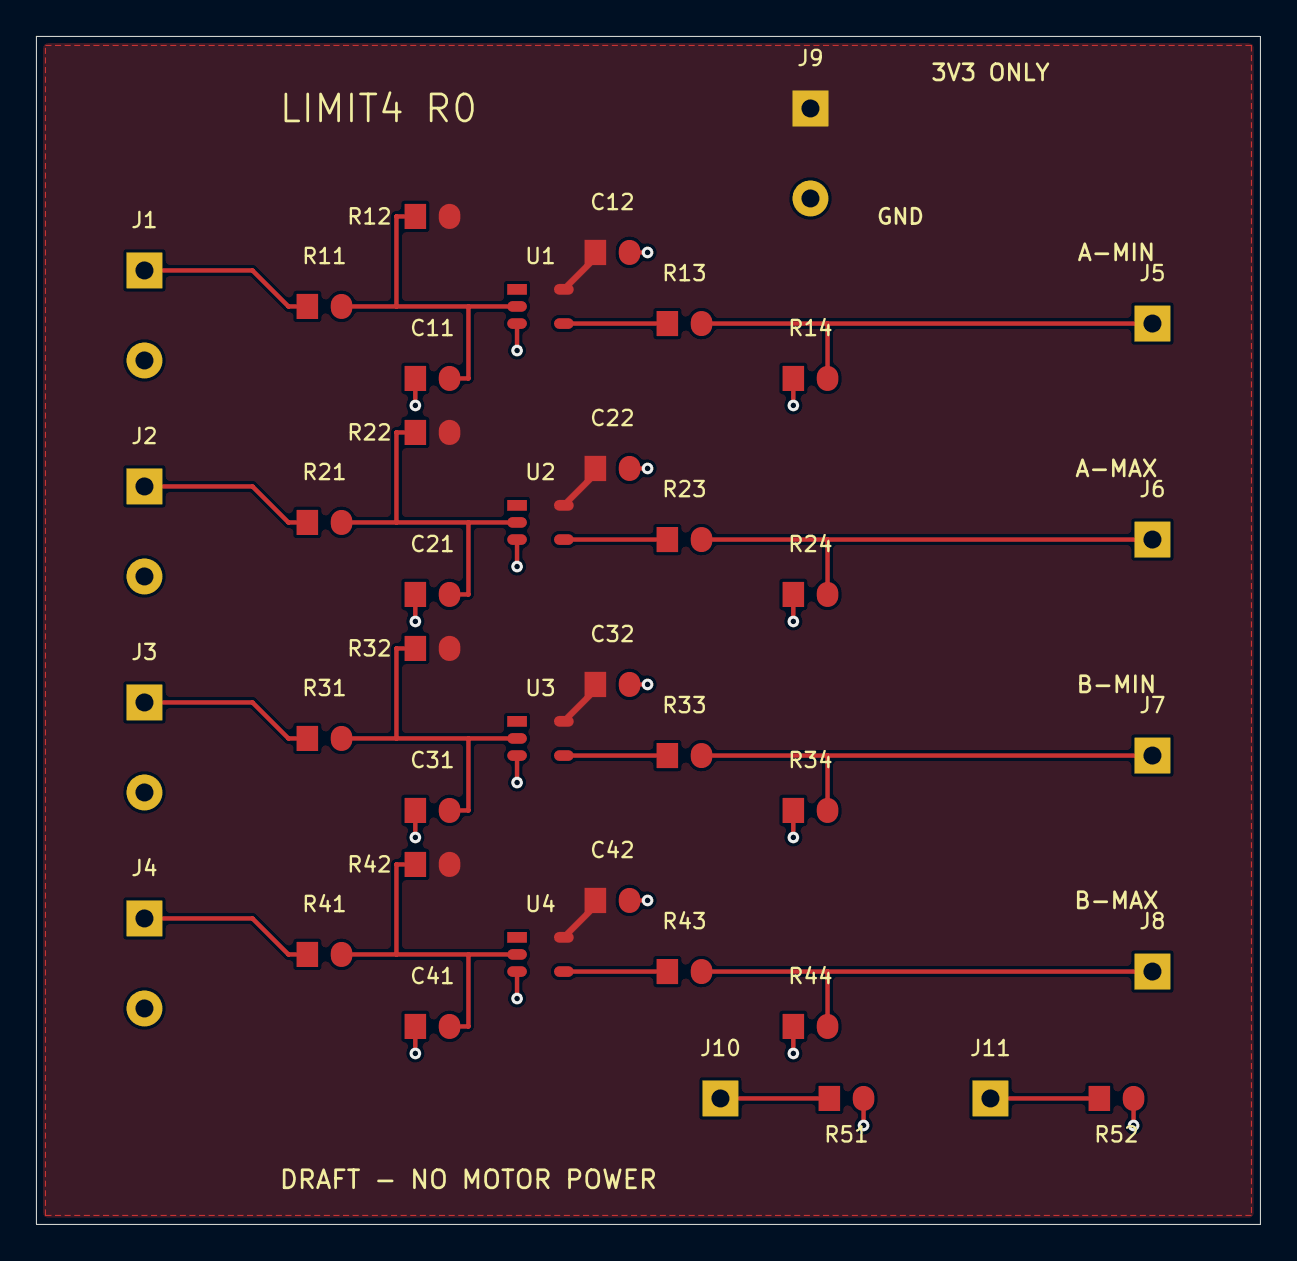
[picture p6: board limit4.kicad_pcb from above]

Board: 2 copper layers, 68.0 x 66.0 mm, 41 parts (0 on the bottom side), 20 nets.

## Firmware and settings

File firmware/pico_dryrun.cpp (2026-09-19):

// SPDX-License-Identifier: MIT
// Bench dry-run firmware: bridge RESET and PWM outputs NEVER enabled.
#include <cstdio>
#include "pico/stdlib.h"
#include "hardware/watchdog.h"
#include "motion.hpp"
#if defined(ENABLE_REAL_DRIVE) && ENABLE_REAL_DRIVE
#error "R0 has no validated power-stage driver. Real drive is intentionally blocked."
#endif
int main(){
 const unsigned outputs[]={12,9,11,13,8,10};
 for(auto pin:outputs){gpio_init(pin);gpio_put(pin,0);gpio_set_dir(pin,GPIO_OUT);}
 const unsigned limits[]={16,17,18,19};
 for(auto pin:limits){gpio_init(pin);gpio_set_dir(pin,GPIO_IN);gpio_disable_pulls(pin);gpio_set_input_hysteresis_enabled(pin,true);}
 gpio_init(14);gpio_set_dir(14,GPIO_IN);gpio_disable_pulls(14);
 stdio_init_all();watchdog_enable(100,true);actuator::Controller c;uint32_t last=0;
 while(true){
   uint32_t now=to_ms_since_boot(get_absolute_time());
   actuator::Inputs in;for(unsigned i=0;i<4;i++)in.allow[i]=gpio_get(limits[i]);in.driver_fault=!gpio_get(14);c.sample(now,in);
   int cmd=getchar_timeout_us(0);
   if(cmd=='a')printf("arm=%d\n",c.arm(now));
   else if(cmd=='h')c.heartbeat(now);
   else if(cmd=='s')c.stop();
   else if(cmd=='1')printf("request A+ accepted=%d\n",c.start(0,1,2000,now));
   else if(cmd=='2')printf("request A- accepted=%d\n",c.start(0,-1,2000,now));
   else if(cmd=='3')printf("request B+ accepted=%d\n",c.start(1,1,2000,now));
   else if(cmd=='4')printf("request B- accepted=%d\n",c.start(1,-1,2000,now));
   for(auto pin:outputs)gpio_put(pin,0);
   if(now-last>=200){last=now;printf("DRY_RUN allow=%d%d%d%d requested=%d,%d physical_drive=OFF\n",in.allow[0],in.allow[1],in.allow[2],in.allow[3],c.requested_direction(0),c.requested_direction(1));}
   watchdog_update();sleep_ms(1);
 }
}

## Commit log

2026-09-19 Publish Rail Transient Inspector v0.1.0 source, tests and reproducible demo build
    AI-assisted implementation. Synthetic validation only; real-instrument validation pending. Preserve Papa Parse attribution and original MIT license. Keep private work archive unchanged.
2026-09-19 Build offline demo and synthetic validation assets [skip ci]
    [synthetic-demo.csv]
2026-09-19 Start isolated dual-actuator hardware engineering branch; pin upstream inspection
    [synthetic-demo.csv]
2026-09-19 Add reproducible native LIMIT4 schematic and routed PCB generator
2026-09-19 Run real KiCad file generation, export and rule inspection on hardware branch
2026-09-19 Add independent limit-state controller, host tests, wiring evidence and prototype release gates
2026-09-19 Fix pcbnew layer-set compatibility and complete capacitor symbol leads
2026-09-19 Use official KiCad 10 stable PPA and apply explicit CAD compatibility fixes
2026-09-19 Use explicit native KiCad IO plugin in standalone pcbnew generation
2026-09-19 Cross-compile output-disabled Pico 2 firmware with pinned Raspberry Pi SDK
2026-09-19 Correct power net flags, align schematic grid, add project-local symbols and tidy PCB labels
2026-09-19 Make channel wiring readable and explicit, with unique net labels and junctions
2026-09-19 Enforce exact pin mapping and fail CI on electrical or PCB rule errors
2026-09-19 Publish LIMIT4 native CAD and actual check records [skip ci]
    [BOM.csv, limit4.kicad_pcb, limit4.kicad_sch]
2026-09-19 Document verified LIMIT4 CAD/firmware results, Chinese review guide and remaining electrical qualification limits
2026-09-19 Rebuild LIMIT4 visitor-facing portfolio and separate engineering reference; clean symbol display without changing circuits
2026-09-19 Publish reviewed symbols and LIMIT4 presentation assets [skip ci]
    [limit4.kicad_pcb, limit4.kicad_sch]
